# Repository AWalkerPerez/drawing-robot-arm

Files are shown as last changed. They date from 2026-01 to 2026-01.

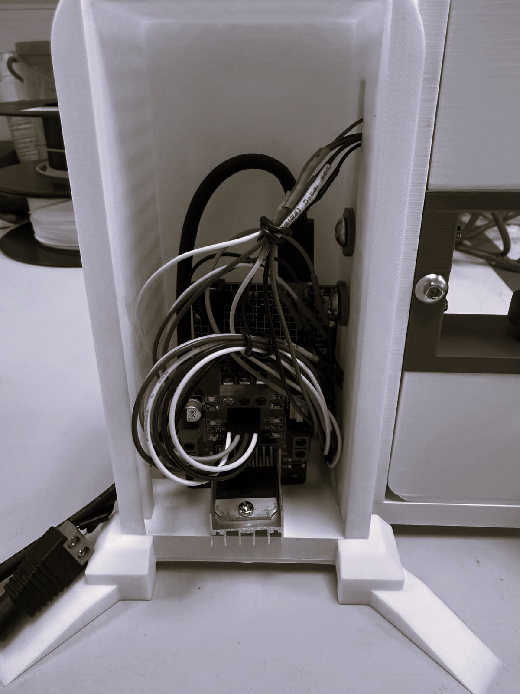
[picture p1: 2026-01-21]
media/photos/wiring_final.jpg

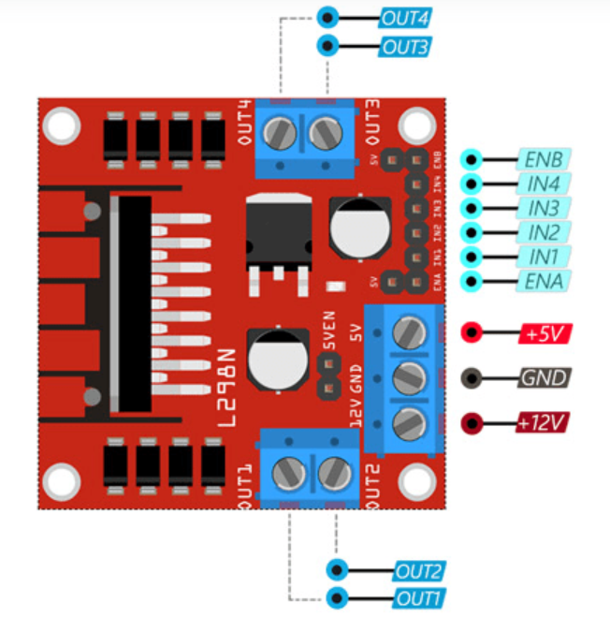
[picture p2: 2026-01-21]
media/diagrams/l298n_pinout.png

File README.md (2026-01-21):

# Small Arm, Big Impact — 2DOF Drawing Robotic Arm

A low-cost 2-degree-of-freedom drawing arm designed for precise motion in a ~156mm x 156mm workspace.
Built with micro servos, an Arduino Uno, and an L298N driver, with analytical IK + PID control and a MATLAB GUI.

## What’s in this repo
- `firmware/` — Arduino code to receive target points and actuate motors
- `matlab/` — GUI + kinematics / plotting scripts
- `cad/` — CAD + printable files (STL/3MF) and assembly notes
- `electronics/` — wiring diagram + parts list
- `report/` — full project report (methods + results)

## Quickstart (typical workflow)
1. Print parts from `cad/`
2. Assemble + wire using `electronics/`
3. Upload Arduino code from `firmware/arduino/`
4. Run the MATLAB GUI in `matlab/gui/` to send (X,Y) targets

## Key methods implemented
- Forward + analytical inverse kinematics
- Differential IK options (Jacobian Transpose / DLS)
- PID tuning per motor
- MATLAB GUI that sends coordinates and plots feedback

## Results
See `report/Final_Applied_Robotics_Report.pdf` for the full evaluation.

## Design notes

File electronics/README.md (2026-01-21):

# Electronics

This folder contains the wiring + component notes for the 2-DOF drawing robot arm.

## What’s in this folder
- `parts_list.md` — exact bill of materials (with quantities)
- `wiring_diagram.png` — wiring diagram for the final build
- `arduino_uno_r4_pinout.png` — Arduino Uno R4 pin reference
- `l298n_pinout.png` — L298N reference pinout (if included)
- `motor_dimensions.png` — motor dimensions (if included)

## System overview
- **Controller:** Arduino Uno R4
- **Motor driver:** L298N dual H-bridge
- **Motors:** 2× DC geared motors with potentiometer feedback
- **Power:** 12V DC supply (12V, 5A)

## Wiring summary (high level)
### Power
1. Connect the **12V supply** to the L298N:
   - Supply **+12V** → L298N `+12V`
   - Supply **GND** → L298N `GND`
2. Connect **Arduino GND** to **L298N GND** (common ground).

> Important: Motors must be powered from the 12V rail through the L298N. Do **not** power motors from the Arduino 5V pin.

### Motors
- Motor 1 → L298N `OUT1` / `OUT2`
- Motor 2 → L298N `OUT3` / `OUT4`

If a motor spins the wrong way, either swap the two motor wires on the output, or invert direction in firmware.

## Arduino pin reference
Use `arduino_uno_r4_pinout.png` as a quick reference for:
- PWM-capable pins (for ENA/ENB)
- Analog inputs (for potentiometer feedback)
- Power pins (5V / GND)

### Control signals (Arduino → L298N)
The L298N uses:
- `IN1, IN2` for Motor 1 direction
- `IN3, IN4` for Motor 2 direction
- `ENA, ENB` for motor speed (PWM)

**Exact pin mapping:** see `firmware/pid_controller/pid_controller.ino` (recommended source of truth).
If you want, you can also document it here once final:

| Signal | L298N pin | Arduino pin |
|---:|---|---|
| Motor 1 PWM | ENA | (fill) |
| Motor 1 dir | IN1 | (fill) |
| Motor 1 dir | IN2 | (fill) |
| Motor 2 PWM | ENB | (fill) |
| Motor 2 dir | IN3 | (fill) |
| Motor 2 dir | IN4 | (fill) |

### Potentiometer feedback (per motor)
Each motor has a potentiometer used for position feedback:
- Pot **VCC** → Arduino **5V**
- Pot **GND** → Arduino **GND**
- Pot **wiper/output** → Arduino **analog input** (e.g., `A0` for motor 1, `A1` for motor 2)

Again, check the `.ino` for the exact analog pins used.

## L298N module notes (common gotchas)
- Many L298N boards have a **5V regulator jumper** (often labelled `5V_EN`).
  - Safest setup: power the L298N logic from the Arduino 5V and only use the 12V rail for motors.
  - If you change jumper settings, double-check the module’s labels so you don’t back-power the Arduino.

- The L298N can get warm. Make sure the heatsink has airflow.

## Troubleshooting
- **Motors don’t move at all**
  - Check common ground (Arduino GND ↔ L298N GND)
  - Confirm 12V is present at the driver input
  - Confirm ENA/ENB are enabled (PWM pin not floating)

- **One motor moves, the other doesn’t**
  - Swap motor outputs to isolate whether it’s wiring vs motor vs code
  - Check that the second motor’s ENB/IN3/IN4 pins match firmware

- **Noisy / jittery feedback**
  - Ensure pot ground is solid
  - Keep pot wires away from motor power wires where possible
  - Shorter wiring helps (direct wiring is good)

## See also
- Firmware: `firmware/`
- MATLAB control/GUI: `matlab/`
- Full write-up: `report/Final_Applied_Robotics_Report.pdf`

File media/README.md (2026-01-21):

# Media

Project visuals used in the root README and report.

## Folders
- `photos/` — real-world prototype photos and GUI output
- `diagrams/` — CAD and reference diagrams
- `plots/` — workspace, accuracy, PID, and manipulability plots
- `demos/` — short MP4 demos

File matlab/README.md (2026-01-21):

# MATLAB

MATLAB code for the 2-DOF drawing robot arm.

This folder contains:
1) A **GUI** that communicates with the Arduino over Serial and plots the motion
2) **Kinematics + analysis** scripts (FK/IK/Jacobian/manipulability) used for offline evaluation and visualisations

---

## Folder structure

Recommended layout:

- `gui/`
  - `GUI.m` — MATLAB GUI: enter a target point (x, y), send to Arduino, plot desired vs actual path

- `control/`
  - `robot_arm_control.m` — offline sandbox for experimenting with control/trajectories (no hardware required)

- `kinematics/`
  - `inverse_kinematics.m` — analytical IK used by the GUI (target x,y → joint angles)
  - `forward_kinematics_version_2.m` — FK used by the GUI (joint angles → x,y for plotting)
  - `forwardKinematics.m` — FK utility (often used by analysis scripts; returns transform / position)
  - `ik_jacobian.m` — Jacobian for 2-link planar model
  - `ik_differential.m` — differential IK update step
  - `Manipulability.m` — manipulability plots + ellipsoids (Jacobian Transpose / DLS)

---

## File entry points (what you actually run)

### Run this (hardware required)
- `gui/GUI.m`  
  Starts the GUI, connects to the Arduino over Serial, sends commands, and plots results.

### Run these (offline / no hardware required)
- `control/robot_arm_control.m`  
  Sandbox for testing trajectories/control ideas locally.
- `kinematics/Manipulability.m`  
  Generates manipulability metrics and ellipsoid plots for Jacobian Transpose and/or DLS (depending on your script settings).

### Helper functions (not run directly)
These are called by the GUI or by the analysis scripts:
- `kinematics/inverse_kinematics.m`
- `kinematics/forward_kinematics_version_2.m`
- `kinematics/forwardKinematics.m`
- `kinematics/ik_jacobian.m`
- `kinematics/ik_differential.m`

---

## Requirements
- MATLAB (R2020b+ recommended)
- Serial support (uses `serialport`, built-in)

---

## Quickstart (Hardware + GUI)

1) Upload the Arduino firmware first  
See: `firmware/README.md`

2) Open MATLAB and set the current folder to `matlab/`

3) Add this folder + subfolders to your MATLAB path:
```matlab
addpath(genpath(pwd))
```
4) Edit the COM port in gui/GUI.m (it’s hardcoded):
```
matlab
s = serialport("COM11", 9600);
```
Change "COM11" to the port your Arduino shows up as.

5) Run the GUI:
```
matlab
GUI
```
---
## What the GUI does (high level)
- Takes a desired end-effector target (x, y)
- Computes joint targets using inverse_kinematics.m
- Sends joint targets over Serial to the Arduino firmware
- Reads measured joint angles back from the Arduino
- Computes the measured end-effector position using forward_kinematics_version_2.m
- Plots desired vs actual
---
## Serial protocol (matches the firmware)
### MATLAB → Arduino (command)
The Arduino parses a command that starts with a character and ends with ;:
`C<theta1>,<theta2>;`
Example:
`C45.00,10.00;`
### Arduino → MATLAB (telemetry)
Arduino streams lines like:
`c<i>,<theta1_meas>,<theta2_meas>`
Example:
`c12,44.63,9.92`
Baud rate: **9600**
---
## Offline analysis scripts (no hardware required)
### Manipulability / ellipsoids
Run:
```matlab
Manipulability
```
This generates manipulability curves and ellipsoids for Jacobian Transpose and/or Damped Least Squares (DLS) depending on your script settings.

### Differential IK utilities
- `ik_jacobian.m` — compute Jacobian at a configuration
- `ik_differential.m` — compute a single joint update for a desired end-effector delta
- `forwardKinematics.m` / `forward_kinematics_version_2.m` — compute end-effector position from joint angles
---
## Units + conventions (important)
- Keep units consistent across GUI input, IK, and FK:
  - If you input mm, link lengths should be mm.
  - If you input m, link lengths should be m.
- Be consistent about degrees vs radians:
  - If firmware expects degrees, keep MATLAB outputs in degrees (or convert explicitly).
A “wrong looking” plot is almost always unit mismatch.
---
## Troubleshooting
- **GUI runs but nothing moves**
  - Check Arduino firmware is uploaded and running
  - Confirm COM port and baud rate (9600)
  - Close Arduino IDE Serial Monitor (it can lock the port)
- **MATLAB errors: “Undefined function …”**
  - Make sure you ran:
  ```matlab
  addpath(genpath(pwd))
  ```
  from inside the `matlab/` folder
**- Plot looks mirrored / inverted**
  - Swap sign conventions in IK/FK or adjust joint angle reference (0° direction)
  - Double-check coordinate frame assumptions (x-right/y-up vs x-right/y-down)
---
## See also
- Firmware upload + pin mapping: `firmware/README.md`
- Wiring + parts list: `electronics/`
- Full project write-up: `report/Final_Applied_Robotics_Report.pdf`

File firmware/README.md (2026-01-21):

# Firmware

Arduino firmware for the 2-DOF drawing robot arm.  
It receives joint angle commands from MATLAB over Serial, runs a PID controller for each motor, and streams back the measured joint angles.

## Location
- Main sketch: `firmware/pid_controller/pid_controller.ino`

## Hardware used
- **Board:** Arduino **Uno R4**
- **Motor driver:** L298N dual H-bridge
- **Motors:** 2× DC geared motors with **quadrature encoder outputs** (A/B)

## How to upload
1. Open `pid_controller.ino` in the Arduino IDE.
2. Select your board:
   - *Arduino Uno R4 Minima* or *Arduino Uno R4 WiFi* (whichever you have)
3. Select the correct **Port**.
4. Click **Upload**.
5. Open Serial Monitor (9600 baud) if you want to view telemetry.

## Pin mapping (as used in the code)

### Motor encoders (quadrature)
| Motor | Encoder A | Encoder B |
|---:|---|---|
| M1 | A3 | A2 |
| M2 | A1 | D11 |

> Note: Encoder A pins use interrupts via `attachInterrupt(...)`. If you change boards/pins, make sure the new pins support interrupts.

### L298N direction pins
| Motor | IN1 | IN2 |
|---:|-----|-----|
| M1 | D4 | D5 |
| M2 | D7 | D8 |

### L298N enable (PWM) pins
| Motor | ENA / ENB | Arduino pin |
|---:|---|---|
| M1 | ENA | D6 |
| M2 | ENB | D9 |

## PID gains (where to change them)
At the top of `pid_controller.ino` you’ll see:

- `Kp_m1`, `Ki_m1`, `Kd_m1`
- `Kp_m2`, `Ki_m2`, `Kd_m2`

Update these values to tune the response.  
There is also an integral windup clamp:

- `windupGuard`

## Serial protocol (MATLAB ↔ Arduino)

### Command format (MATLAB → Arduino)
The Arduino expects joint targets (in **degrees**) in this format:

`C<theta1>,<theta4>;`

Example:
`C45.00,10.00;`

Notes:
- The leading `C` is required.
- Values are parsed as floats.
- The command must end with `;`

### Telemetry format (Arduino → MATLAB)
The Arduino continuously streams:

`c<i>,<theta1_meas>,<theta4_meas>\r\n`

Example:
`c12,44.63,9.92`

Where:
- `i` is a counter
- `theta1_meas`, `theta4_meas` are the measured joint angles (degrees)

## Using with MATLAB
The MATLAB GUI sends commands in the correct `C..., ...;` format and parses `c...` telemetry.

- GUI script: `matlab/gui/GUI.m`
- **Important:** update the COM port in `GUI.m` (it’s currently hardcoded, e.g. `COM11`).

## Troubleshooting
- **Nothing moves**
  - Confirm L298N has 12V power
  - Confirm **common ground** (Arduino GND ↔ L298N GND)
  - Check ENA/ENB pins are connected to PWM pins (D6, D9)
- **One motor spins the wrong direction**
  - Swap OUT wires for that motor on the L298N, or invert direction logic in code
- **No serial data in MATLAB**
  - Confirm baud rate is **9600**
  - Confirm correct COM port and that Arduino IDE Serial Monitor is closed (it can “steal” the port)

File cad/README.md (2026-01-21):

# CAD

## Folders
- `fusion360/` — editable source CAD (Fusion 360)
- `print_files/3mf/` — print-ready 3MF exports (recommended)
- `print_files/stl/` — print-ready STL exports (most compatible)
- `renders/` — images used in the main README

## Notes
3MF files are the easiest way to reproduce the exact prints.
Fusion 360 files are provided for modification/customisation.

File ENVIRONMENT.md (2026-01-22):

# Environment

This project is implemented using **MATLAB** and **Arduino** (no Python dependencies required).

## Tested setup
- **OS:** Windows 10/11 (recommended)
- **MATLAB:** R2020b+ (any recent version should work)
- **Arduino IDE:** 2.x
- **Board:** Arduino **Uno R4** (Minima or WiFi)
- **Motor driver:** L298N dual H-bridge
- **Power supply:** 12V DC, 5A (60W)

## MATLAB requirements
- MATLAB with support for `serialport` (built-in)
- No additional toolboxes are required for the provided scripts

### MATLAB path setup
From the `matlab/` folder:
```matlab
addpath(genpath(pwd))
```
### Arduino requirements
- Install Arduino IDE 2.x
- In **Tools** → **Board**, select:
  - Arduino Uno R4 Minima or Arduino Uno R4 WiFi (depending on your board)
- Select the correct **Port**
- Upload: `firmware/pid_controller/pid_controller.ino`

### Serial communication
- Baud rate: **9600**
- The COM port is hardcoded in `matlab/gui/GUI.m` and must be updated to match your machine (e.g., `COM5`, `COM11`, etc.)

### File formats (CAD)
- Editable Fusion 360 exports: `.f3d` (single design) / `.f3z` (assembly)
- Print exports: `.3mf` and/or `.stl`

### Notes / common issues
- Close the Arduino IDE Serial Monitor when running the MATLAB GUI (it can lock the serial port).
- Ensure a **common ground** between the Arduino and motor driver.
---
## Setup (Quickstart)
This is the fastest path from cloning the repo to running a demo.
### 1) Hardware + wiring
**1.** Assemble the robot (see the report for mechanical build context).

**2.** Wire the electronics:
  - See `electronics/README.md`
  - Use `electronics/wiring_diagram.png`
  - Use `electronics/arduino_uno_r4_pinout.png` as a pin reference.

**Power checklist**
- 12V supply powers the L298N (+12V and GND)
- Arduino and L298N share a common GND
- Motors connect to L298N outputs (OUT1/OUT2 and OUT3/OUT4)

### 2) Upload firmware (Arduino)
**1.** Open Arduino IDE.

**2.** Open: `firmware/pid_controller/pid_controller.ino`.

**3.** Select your board (Uno R4 Minima/WiFi) and Port.

**4.** Click **Upload**.

### 3) Run MATLAB GUI
**1.** Open MATLAB.

**2.** Set current folder to `matlab/`.

**3.** Add paths:
```matlab
addpath(genpath(pwd))
```
**4.** Open `matlab/gui/GUI.m` and update the COM port:
```matlab
s = serialport("COM11", 9600);
```
**5.** Run:
```matlab
GUI
```
### 4) Demo
- Enter a target point (x, y) in the GUI and press **Send**
- The GUI sends commands to the Arduino and plots desired vs actual motion
---
### Troubleshooting
- If MATLAB can’t connect to the serial port:
  - Close Arduino IDE Serial Monitor
  - Double-check COM port and baud rate (9600)
- If motors don’t move:
  - Confirm 12V supply is live at the L298N
  - Confirm common ground (Arduino GND ↔ L298N GND)
  - Confirm ENA/ENB and IN1–IN4 wiring matches the firmware pin mapping

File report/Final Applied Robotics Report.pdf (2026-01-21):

SMALL ARM, BIG IMPACT: AL THE DRAWING ROBOTIC ARM

### Andrea Walker Perez Kings College London

ABSTRACT
This paper presents the design and development of a two-
degree-of-freedom robotic arm | tailored for | precise
applications within a 156 mm x 156 mm workspace. The arm demonstrates potential for use in medical scenarios such as fine motor surgical tasks and precision prototyping. The aim is to create an affordable, compact system integrating efficient control strategies. The robot integrates micro servo motors and a custom CAD design, controlled by an Arduino Uno and L298N motor controller. Forward and inverse kinematics were derived for accurate motion planning, and PID tuning was employed to optimise the stability and accuracy of the system. Experiments were conducted to evaluate the arm’s performance under varied loads, PID settings, and predefined trajectories. The robotic arm achieved an average deviation of less than 2 mm in accuracy tests and exhibited reliable repeatability under varying conditions. Experimental results demonstrate a clear trade-off between speed and precision, with optimal PID gains minimising oscillations and ensuring stability.
This robotic system provides a foundation for low-cost, high-precision applications in robotics. Future enhancements will address system limitations such as oscillations under high loads and explore dynamic control strategies to expand its operational capabilities.

### 1. INTRODUCTION

Robotics in precision applications, particularly in medical fields, is a fast-evolving domain. With increasing demand for accuracy, affordability, and adaptability, two critical questions emerge:
1. Can robotic systems replicate the fine motor skills required in precision tasks such as surgeries?
2. How can low-cost robotic arms maintain high precision and stability under varying conditions?
Advancements in robotics have proven their ability to perform intricate tasks traditionally reserved for humans. The Da Vinci Surgical System has revolutionised surgery by enabling minimally invasive procedures with millimetre-scale accuracy [1]. Low-cost solutions incorporating modern control techniques, such as PID and kinematic modelling, make robotic precision more accessible.
While promising, affordability often comes at the cost of robustness and precision. Unlike high-end systems, low-cost robotic arms frequently struggle with stability under dynamic conditions and precision in repeatability. Additionally,
integrating | compact | designs | with | high-performance
electronics and motors remains challenging.
The integration of efficient control strategies with modular hardware designs offers a pathway to making robotic precision more accessible. By addressing stability and precision trade-offs, low-cost robots can extend their applications beyond prototyping into fields like medical assistance and microfabrication.

### 1.1. Aim and Objectives

The aim was to design, build, and evaluate a two-degree-of-freedom robotic arm capable of precise drawing operation within a defined workspace.
Specific objectives include:
- Develop a modular CAD design integrating micro servos, thrust bearings, and a secure pen holder.
- Implement forward and inverse kinematics for accurate motion planning.
- Optimise PID control to balance speed, precision, and stability.
- Evaluate performance through experiments focusing on accuracy, speed, and load-bearing capacity.

### 2. METHODOLOGY

This section details the design, development, and testing methodologies for the robotic system designed for medical applications. The focus was on achieving high precision, stability, and a wide range of motion. The system combines CAD design, hardware integration, kinematic analysis, control strategies, and experimental validation.

### 2.1 CAD Design and 3D Printing

The robotic arm was designed as a parallel SCARA configuration with an extension holding the end effector, tailored for precision and compactness. The CAD design comprises three main components: the base, the arm, and the protective housing. The arm features four links: two vertically stacked links directly connected to motors, maximising the range of motion and compactness, and two additional links extending the reach of the end effector. The parallel arrangement optimises workspace usage while maintaining high accuracy and mechanical robustness.
The base provides a robust foundation, securely housing the motors and control electronics to ensure consistent performance during operation. To enhance the grounding of the arms, the motor-connected links were equipped with ratcheting gears, allowing manual adjustments without affecting the motor’s position.

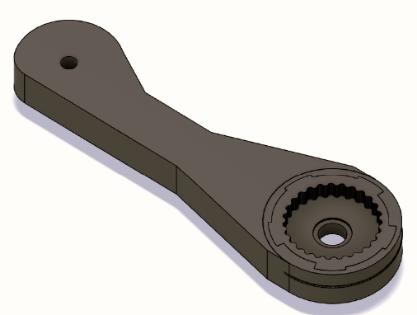
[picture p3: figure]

Figure 1 Ratcheting Gear Design

One motor-driven link is connected to an intermediate one, supporting the pen-holding assembly. In contrast, the final link bridges the end-effector and the second motor-driven link, completing the parallel SCARA-like mechanism. Figure 1 illustrates the arm’s configuration.
The protective housing was designed to enclose the Arduino Uno and motor drivers, offering environmental protection while ensuring accessibility for maintenance. Features like a sliding door allow for easy access to electronics without compromising the overall design’s integrity.
The design underwent iterative refinement using Fusion 360, where simulations validated key aspects such as mechanical strength, range of motion, and component interactions. After finalising each design, the CAD models were exported in the .3mf file format, which preserves intricate geometries and ensures compatibility with the 3D printing process.
3D printing was performed using Bamboo Studio, where the .3mf files were imported for slicing and G-code generation. The printing parameters were selected to balance dimensional accuracy and structural integrity. A layer height of 0.2 mm was used to achieve a smooth surface finish, while an infill density of 40% provided the necessary strength and reduced material usage. PLA was chosen as the primary material due to its favourable mechanical properties, lightweight nature, and ease of use. Supports were strategically applied to maintain precision during printing. Preliminary test prints were conducted to evaluate the dimensional accuracy of the 3D printed components compared to the CAD designs on Fusion 360. These tests ensure that the printed dimensions closely matched the intended specifications and allowed for fine-tuning of the design to account for such discrepancies, ensuring that critical dimensions met the necessary tolerances for proper assembly and functionality.

### 2.2 Hardware Integration

The robotic system’s hardware was designed with precision and compactness in mind. At its core, the system comprises two micro servo motors controlled by an Arduino Uno, which interfaces with an L298N motor driver. This integration was essential for ensuring precise motion control of the robotic arm. The Arduino Uno serves as the central control unit, executing commands and managing the motor signals. It connects directly to the L298N motor driver through its digital pins. These connections include ENA, ENB, IN1, IN2, IN3, and IN4, which transmit the necessary Pulse Width Modulation (PWM) and directional signals for the motors.

The motors themselves are powered via the OUT1/OUT2 and OUT3/OUT4 outputs of the L298N, ensuring smooth operation. The L298N receives power from an external 12V supply, with its GND connected to both the Arduino and the supply for common ground.
To enhance stability and efficiency, thrust bearings were used in the joints directly connected to the motors. These bearings handle the axial loads effectively, reducing wear and tear while transmitting torque reliably to the robotic arm. For the other joints, ball bearings were chosen for their ability to minimise friction and ensure smooth rotational motion, crucial for maintaining precision during operation.
Wiring was carefully organised and routed through protective housing to minimise clutter and facilitate troubleshooting. Cable ties were used to secure connections, and wires were routed away from moving parts to prevent damage during operation. The servos were powered by an external 5V power supply, ensuring sufficient torque and consistent operation without overloading the Arduino’s onboard regulator.
A simplified schematic wiring diagram is provided in Figure 2, illustrating the connections between the components. The diagram highlights the integration of the Arduino, L298N motor driver, motors, and the external power supply, with clear labelling of all pins and connections. This setup ensures reliability and ease of replication.

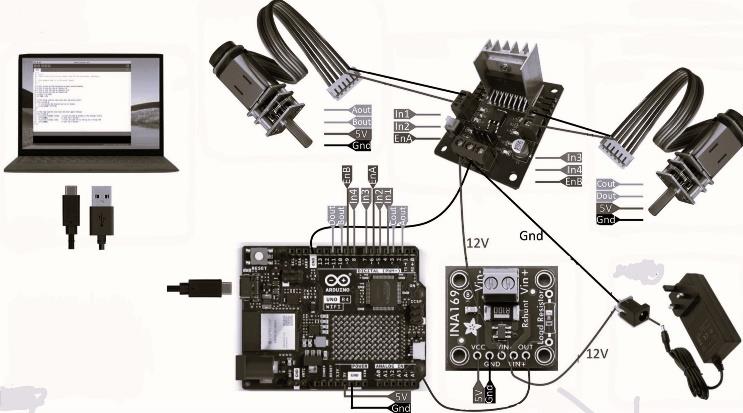
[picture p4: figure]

Figure 2 Wiring Diagram

### 2.3 Kinematics

2.3.1. Forward Kinematics
Forward kinematics was used to calculate the end-effector’s position in the 2D workspace based on the joint angles (θ1 and θ2) and the lengths of the robot arm’s links directly connected to the motors (l1 and l4).
The end-effector’s coordinates (x, y) were computed using the following equations:
x = l1cosθ1 + l4cosθ4 +lexcosθex
= l2cosθ2 + l3cosθ3 + lexcosθex y = l1sinθ1 + l4sinθ4 + lexcosθex
= l2sinθ2 + l3sinθ3 + lexsinθex Here, l1 and l4 represent the two links extending from the motors, while l2, l3, and lex are the links connecting the dependent joints to the end-effector. The angles θ1 and θ4 are measured relative to the horizontal baseline and serve as the primary independent joint angles. The dependent angles, θ2, θ3, and θex, are proportional to the main angles, with θ2 = θex = θ4 and θ3 = θ1.
The workspace of the robotic arm was analysed using forward kinematics, considering the lengths of the links and the joint angle limits. As shown in Figure 3, the theoretical workspace, represented by the dotted curve, highlights all reachable positions. Within this theoretical workspace lies the operational workspace, a 156 mm x 156 mm square area selected for precision tasks. The operational workspace has an offset of approximately 110 mm from the centre of the robot, corresponding to the length of l1, which creates a gap between the centre and the reachable area.

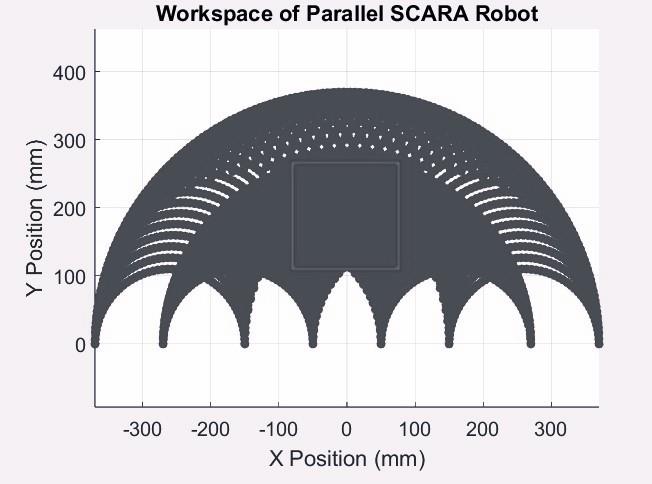
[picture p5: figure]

Figure 3 Theoretical and Operational Workspaces of the Robotic Arm

The derivation of the forward kinematics equations and methodology for determining the workspace were guided by principles discussed in the work of Le et al. [2], which provide a foundational approach to analysing planar parallel manipulators.
2.3.2. Analytical Inverse Kinematics
The analytical inverse kinematics for the robotic arm were derived to calculate the required joint angles (θ1 and θ4) based on the derived end-effector position (x,y) within the 2D workspace. This method relies on trigonometric relationships and the geometry of the parallel SCARA configuration, ensuring high precision in computing the joint parameters. The inverse kinematics equations were derived using the lengths of the robot’s links and the constraints imposed by the arm’s geometry. These equations ensure that each desired position is mapped to a unique set of joint angles. The process involves calculating the distance from the origin to the intersection between both paths:
r = √x
2 + y
2 | (1)
Then, using the cosine rule, the intermediary angles are derived:

A = cos⁻¹

(

l1

2+r
2−l4

2

2l1r

) | (2)

B = cos⁻¹

(

l1

2+l4

2+r
2

2l1l4

) | (3)
E = 180 − A −D | (4)
F = B − E | (5)

To account for the offset:
w = (l5 − l4
) cos(F) | (6)

z = (l5 − l4

) sin(F) | (7)

The corrected position of the end-effector point is:

x2 = x − w | (8)

y2

= y − z | (9)

The angle D represents the orientation of the target position relative to the origin. To ensure the robot operates within its physical constraints and avoids unsafe configurations, the following conditions are applied:
- For
(x ≥ 0, y ≥ 0):D = tan⁻¹
(

y
x
⁄ ) | (10)
- For

(x < 0, y ≥ 0):D = 180 − tan⁻¹
(

y
−x
⁄ ) | (11)
- For

(x ≥ 0, y < 0):D = tan⁻¹
(

y
x
| | ⁄ ) | (12)
- For
(x < 0, y < 0): This configuration is unreachable and should return and error.
Limiting D ensured that the computed angles remain within the robot’s workspace and prevents it from attempting to move to positions that could damage the hardware. Finally, the angles G and H, required to resolve the kinematics of the arm, are calculated using the cosine rule as follows:

G = cos⁻¹

(

r

| 2+r2

2−(l5−l4
| | )
| | 2
| 2rr2 | ) | (13)

H = cos⁻¹

(

l2

| 2+r2 2−l1

2

| 2l2r2
) | (14)

Finally, the joint angles are defined as follows:
θ1 = D +A | (15) | θ4 = (D +G) −H | (16)

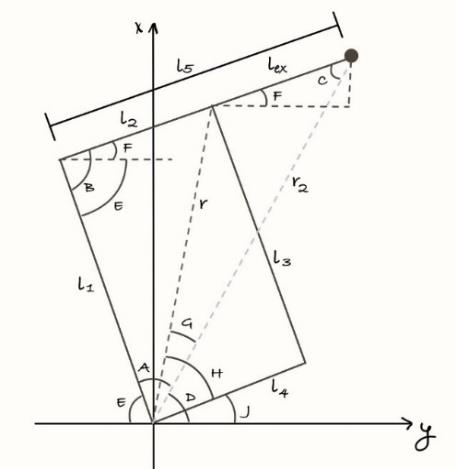
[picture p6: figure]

Figure 4 Analytical Inverse Kinematic Diagram

The derived equations account for the dependency of the secondary joint angles on the primary joint angles as mentioned in section 2.3.1. This dependency ensures that the
arm | operates | cohesively, | maintaining | its | parallel
configuration. The final equations were validated through MATLAB simulations, where test cases confirmed that the computed angles accurately positioned the end-effector within the desired workspace. In section 3 you can see the GitHub repository link with all the code implementing this.
2.3.3. Differential Inverse Kinematics and Manipulability The robotic arm’s motion and manipulability were analysed using differential inverse kinematics methods, specifically the Jacobian transpose method and the damped least squares (DLS) method. These approaches were implemented to ensure accurate tracking of the desired end-effector trajectories while maintaining stability and avoiding singularities within the workspace.
The Jacobian matrix, derived as a function of the joint angles and link lengths, provides a relationship between the joint velocities and the end-effector velocity in Cartesian space [3]. Its form is given as:

J = [

−r1 sin(θ1

) −r2 sin(θ2

)
r1 cos(θ1
| ) | −r2 sin(θ2

)

] | (17)

, where r1 and r2 represent the respective link lengths. This matrix not only facilitates the computation of joint velocities but also provides insight into the manipulability of the robotic arm at various configurations. The manipulability at a specific configuration is defined as the square root of the determinant of JJT
, which quantifies the arm’s ability to perform precise motions in multiple directions. Higher manipulability values correspond to greater ability and flexibility in motion.
The DLS method computed joint velocity corrections, enhancing numerical stability near singularities [3]. This method modifies the pseudo-inverse of the Jacobian by introducing a damping term, ensuring that the control law remains stable even in configurations where the Jacobian matrix approaches singularity [3]. The control law is defined as:

∆q = (J

T
J +λ

2
I)

−1
J

T
| | e | | | (18)

, where ∆q represents the joint velocity corrections, e is the error between the desired and current end-effector positions, λ is the damping factor, and I is the identity matrix. The damping factor was tuned experimentally to balance responsiveness and stability, ensuring smooth trajectory tracking.
As an alternative, the Jacobian transpose method was used. This approach simplifies computation by avoiding matrix inversion, making it computationally efficient but less robust near singularities [3]. The control law for the Jacobian transpose method is expressed as:
∆q = kJ

T
e | | | | | (19)

, where k is the gain factor. While Jacobian transpose is advantageous for its simplicity, it was primarily used for configurations away from singularities, where robustness was less critical.

### 2.4 PID Control

PID control was implemented to ensure smooth, precise, and responsive positioning of the servo motors in the robotic arm. The control law is expressed as

u(t) = Kpe(t) + Kd

| | de(t)
| | dt
+ Ki ∫ e dt + | (20)

, where e(t) is the error between the desired and actual position of the motor [4]. Kp, Ki, and Kd are the proportional, integral, and derivative gains. Graph 1 provides theoretical damping scenarios that may arise when tuning the PID gains and serves as a guide to understanding the influence of each. In an underdamped response, the system is sensitive to errors and tends to overshoot the setpoint with oscillations before eventually settling. This scenario typically arises when the proportional gain is too high, resulting in a system that reacts aggressively to deviations. In contrast, an overdamped response is characterised by a slow and conservative approach to the setpoint, with no overshoot. This behaviour often results from overly cautious tuning, such as a low Kp or an excessively high Kd. A critically damped response lies at the boundary between these two extremes, where the system reaches the setpoint without oscillating. However, it is often too slow for dynamic systems that require both speed and precision.
The dashed curve on the graph represents an optimally tuned PID system, which achieves a slightly underdamped response. This provides a balanced trade-off between responsiveness and stability, allowing the system to reach the setpoint quickly with minimal overshoot and without significant oscillations. This is typically the desired behaviour for robotic systems performing precision tasks such as drawing.
Each component of the PID controller contributes uniquely to the system’s behaviour. The proportional term reacts proportionally to the current error, providing immediate
corrective | action. | While | increasing | Kp | improves
responsiveness, it also risks overshoot and instability if set too high. The integral term addresses steady-state errors by considering the accumulation of past errors, correcting persistent offsets. However, excessive Ki can introduce oscillations due to overcompensation. Finally, the derivative term predicts future errors by responding to the rate of change of the error, effectively dampening oscillations and smoothing the system’s approach to the setpoint.
Using this theoretical framework as a guide, the PID tuning process was conducted systematically. The process began with tuning Kp, while Ki and Kd were initially set to zero. Kp was incrementally varies within range of 1 t. Once a satisfactory value was determined, Ki was introduced between 0 and 20. Finally, Kd was incorporated to refine the transient response within a range of 0 to 20.
This structured approach ensured that each gain was tuned in isolation before combining them to achieve a balanced and effective PID control.
The PID tuning process aimed to optimise the PID parameters to balance speed and accuracy in the robotic arm’s movements. The process began with a focus on the Kp, which varied incrementally from 1 to 50 whilst keeping Ki = 0 and Kd = 0.
The integral gain (Ki) was introduced to mitigate overshoot and address steady-state errors, ranging from 0 to 20. Then kd ranging from 0 to 20.

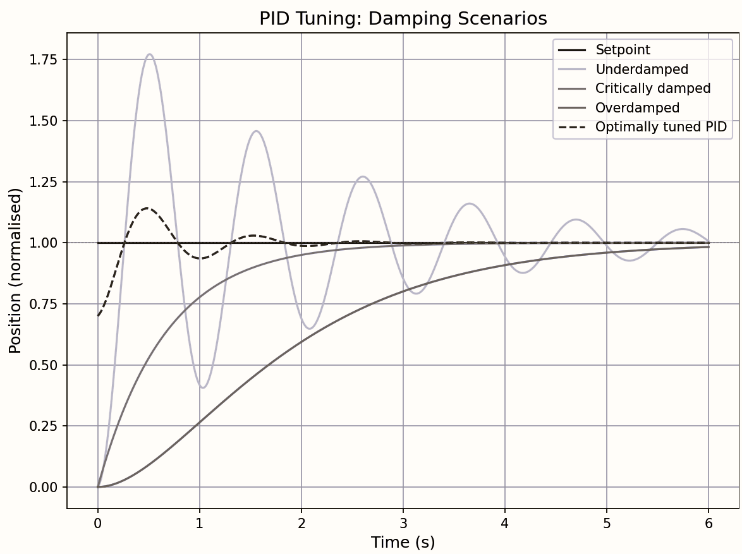
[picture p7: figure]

Graph 1 Damping Scenarios during PID Tuning (adapted from [5])

### 2.5 High-Level Control and GUI Implementation

The high-level control of the robotic system involves a structured workflow that bridges the gap between user commands and precise robotic movements. Figure 5 shows this workflow, which includes command input via a graphical user interface (GUI), real-time data processing, and the computation of joint angles for robot motion using inverse kinematics.

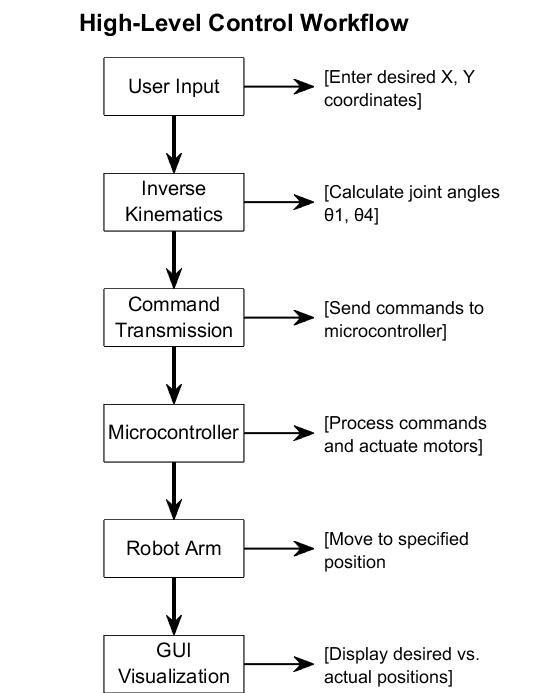
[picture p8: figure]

Figure 5 High-Level Control Workflow of the Robotic System

The GUI, developed in MATLAB, allows users to input desired Cartesian coordinates (X, Y) for the robot’s end-effector position. These inputs are processed to compute the required joint angles (θ1, θ4) using the analytical inverse kinematics method. Computed angles are then formatted into commands and transmitted to the microcontroller via serial
communication. | On | receiving | commands, | the
microcontroller allows the robot to move to the specified position. Simultaneously, the robot’s actual position, derived using forward kinematics, is sent back to the GUI for real-time plotting and comparison with the desired position. The GUI interface features input fields for X and Y coordinates, a send button for command transmission, and a dynamically updating plot area for visualising the robot’s motion, as shown in Figure 6. Additionally, a real-time data stream from the microcontroller updates the end-effector position at a fixed rate, enabling continuous feedback during operation.

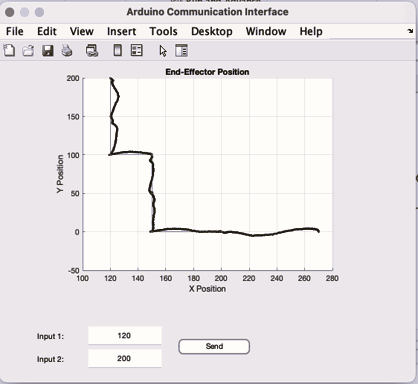
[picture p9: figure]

Figure 6 GUI Interface

The GUI was critical in supporting the experiments described in section 2.6. By enabling precise position control and real-time monitoring, it facilitated the execution of the
experiments. | The | MATLAB | code | for | the | GUI
implementation is included in the GitHub repository linked at the end of section 3.

### 2.6 Experimental Design

Two experiments were designed to evaluate the robot’s performance.
2.6.1. Accuracy Test
The first experiment was conducted to evaluate the robotic arm’s precision in reaching predefined target positions within its workspace. Eight target positions were selected strategically to cover various regions of the workspace, including central locations, edges, and corners. The target positions were defined by their coordinates (X desired, Y desired) and were chosen to ensure a comprehensive assessment of the arm’s ability to accurately traverse its full range of motion.
The robotic arm was programmed to move to each target position using the inverse kinematics model developed in section 2.3.2. Upon reaching a target position, the arm’s actual coordinates (X actual, Y actual) were measured manually using a digital calliper. These measurements were taken at the end-effector, ensuring high precision in capturing the arm’s true location. The deviation between the desired and actual coordinates was recorded for each position.
To assess repeatability and consistency, the experiment was repeated four times for each target position. Between trials, the arm was reset to a neutral home position to ensure the results reflected the arm’s ability to accurately reach the target rather than any systematic drift or accumulated error. The data from these tests were used to calculate the positional error at each target, as well as the mean and standard deviation of the errors across all trials.
2.6.2. Speed vs. Accuracy Test
The second experiment was designed to investigate the trade-off between movement speed and positional accuracy. This test aimed to evaluate how varying the PID controller’s gains affects the arm’s ability to move quickly while maintaining precision. By tuning the proportional, integral, and derivative gains, the speed of the arm’s movements could be increased or decreased, influencing its ability to accurately reach a target. For this test, a subset of the target positions used in the accuracy test was selected, focusing on positions that represented both central and edge locations within the workspace. The PID gains were incrementally adjusted to achieve three different speed settings: low speed (high damping, conservative motion), medium speed (balanced damping and responsiveness), and high speed (low damping, aggressive motion). Each speed setting represented a unique combination of Kp, Ki, and Kd, as determined during the tuning process described in section 2.4. At each speed setting, the arm was programmed to move to the predefined target positions, and its actual coordinates (X actual, Y actual) were recorded as in the accuracy test. The positional error was calculated for each target and analysed to identify any trends between movement speed and accuracy. The experiment was repeated three times for each speed setting to ensure the results were consistent and reliable. In addition to recording positional errors, the time taken to move from the home position to each target was measured using a stopwatch. This allowed for a direct comparison of movement speed and accuracy. This experiment aimed to quantify the relationship between speed and accuracy, highlighting the influence of PID tuning on the robotic arm’s performance.

### 3. RESULTS 3.1 Final CAD Design, 3D Printing, and Wiring

The robotic arm was successfully designed, fabricated, and assembled, meeting the specified requirements for precision, functionality, and ease of integration. The CAD model, shown in Figure 8, was developed using Fusion 360 and features a compact and modular design that optimises workspace use while ensuring structural stability. The arm incorporates a 2DOF mechanism, enabling precise movements within the 156 mm x 156 mm workspace. Integrated cable routing channels and secure mounts for the micro servo motors were included to minimise wire entanglements and improve reliability. Additionally, the
design | emphasised | modularity, | allowing | individual
components to be replaced or upgraded with minimal effort.

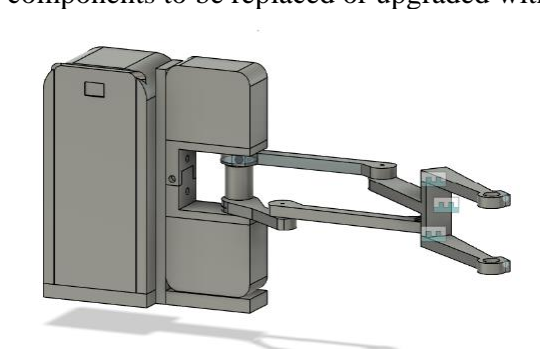
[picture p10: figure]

Figure 7 Final CAD Design in Fusion 360

Once the CAD design was finalised, the robotic arm components were fabricated using 3D printing. The printed model is displayed in Figure 9. The components were printed using PLA, selected for their balance between lightweight properties and sufficient structural strength. The 3D-printed parts demonstrated excellent dimensional accuracy, ensuring proper alignment and fit during assembly. No post-processing was required, as the tolerances were adhered to during the design phase.

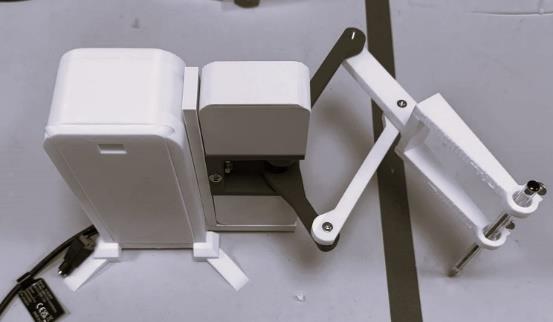
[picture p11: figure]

Figure 8 Final 3D Printed Robotic Arm

The hardware and wiring were organised within the base of the robotic arm, as shown in Figure 10. The design of the base provided sufficient space for all control electronics, including the Arduino Uno, L298N motor controller, and additional components. Wiring was routed through the channels incorporated into the CAD model, ensuring a tidy and secure layout. This approach reduced clutter and minimised the risk of disconnections or signal interference during operation. Cooling considerations were also considered, with the arrangement allowing sufficient airflow around the components.

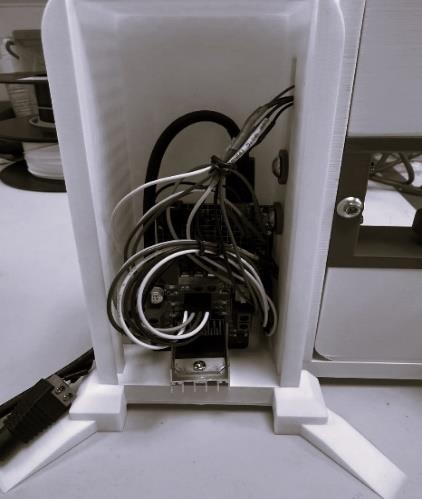
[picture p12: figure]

Figure 9 Final Wiring

### 3.2 Analytical vs Differential Inverse Kinematics

The performance of the robotic arm was evaluated using three methods for computing joint angles and trajectory tracking: analytical inverse kinematics, the Jacobian Transpose method, and the Damped Least Squares (DLS) method. Each method was assessed based on its ability to compute joint
angles, | track | desired | trajectories, | and | maintain
manipulability. The analytical inverse kinematics method provided direct computation of joint angles using geometric and trigonometric relationships. The results, illustrated in Graph 2, demonstrate the arm configuration aligning precisely with the desired position within the workspace. This method generated exact solutions for all tested target positions, provided they were within the workspace and not near singularities.

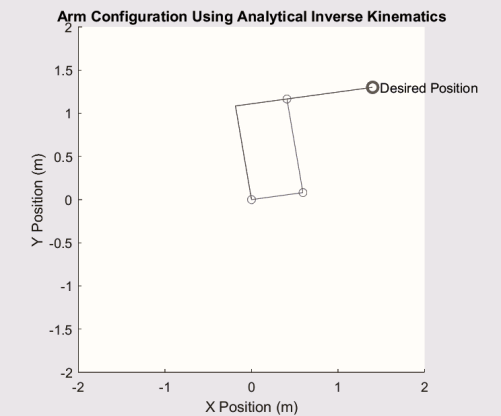
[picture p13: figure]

Graph 2 Analytical Inverse Kinematics Output

The Jacobian Transpose method uses an iterative approach to compute joint angle corrections by multiplying the Jacobian matrix transpose with the positional error. Graph 3 depicts the robot arm’s motion, and the manipulability of ellipsoids generated during trajectory tracking using this method. The manipulability values computed along the trajectory are shown in Graph 4, which highlights changes in manipulability as the arm crosses various configurations.

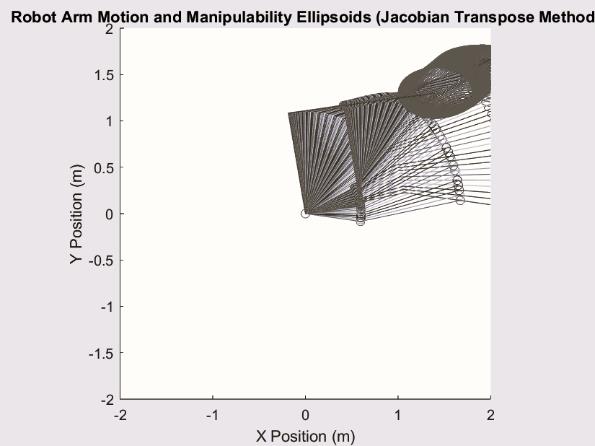
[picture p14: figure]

Graph 3 Jacobian Transpose Output

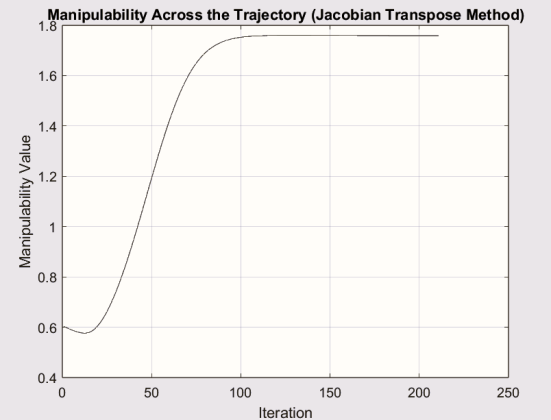
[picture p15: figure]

Graph 4 Manipulability when using Jacobian Transpose

The Damped Least Squared (DLS) method incorporated a damping factor to stabilise the pseudo-inverse of the Jacobian matrix, allowing it to handle singularities more effectively. The motion and manipulability of ellipsoids produced using this method are presented in Graph 5, showing smoother and more consistent ellipsoids compared to the Jacobian Transpose method. Graph 6 illustrates the manipulability values along the trajectory when using the DLS method, which remained stable across all configurations tested.

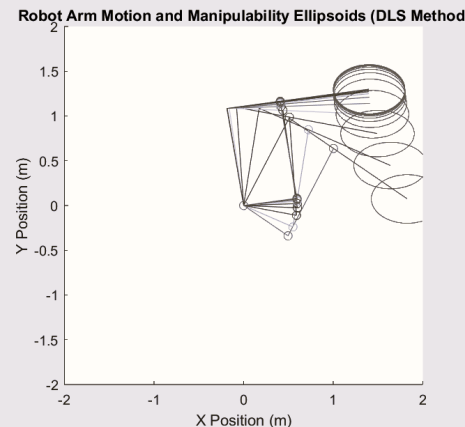
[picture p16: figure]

Graph 5 DLS method Output

Graph 6 Manipulability when using DLS method

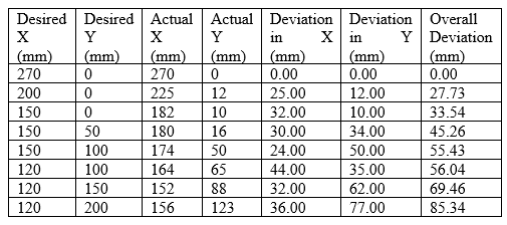
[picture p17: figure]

The MATLAB code for implementing these methods is included in the GitHub repository link at the end of this section.

### 3.3. PID Tuning

The results of the PID tuning tests for the robotic arm are summarised in the table below. The table includes the system response metrics for different combinations of Kp, Ki, and Kd gains, tested on each motor. Key performance metrics measured include the steady-state value, steady-state error, rise time, peak time, peak overshoot, and settling time.

Table 1 PID Tuning Results

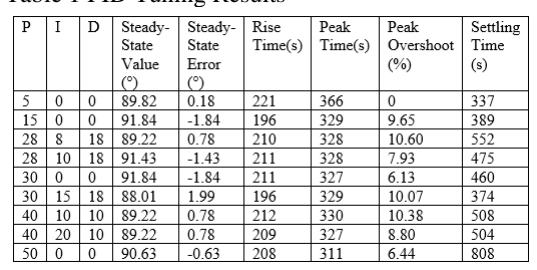
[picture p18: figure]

The corresponding system response graphs for each tuning configuration are presented in Appendix A in Graphs 8-14, showing the angular position versus time for both motors under each set of gains. Optimal PID gains are 28-10-18 for motor 1 and 25-6-18 for motor 2 shown visually in Graph 8.

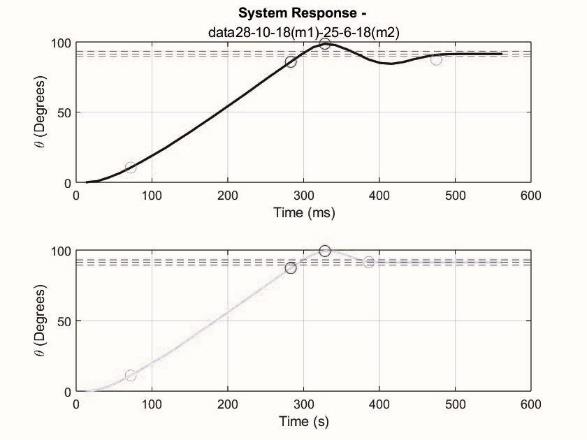
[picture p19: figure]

Graph 7 PID Response for Motor 1 and Motor 2 with PID Gains 28-10-18 and 25-6-18 respectively

### 3.2 Accuracy Test

Table 2 contains the desired and actual positions when sent to multiple points for one of the iterations. It also contains the deviation in each axis and the overall deviation. Graph 9 shows visually all desired and actual positions in that same iteration.
Graph 8 is a bar graph summarising the average deviation for each position.
The average deviation across all trials was calculated as 4.5 mm in the X-axis and 6.7 mm in the Y-axis.

Table 2 Actual and Desired Positions from the robot when going to different points for the accuracy test

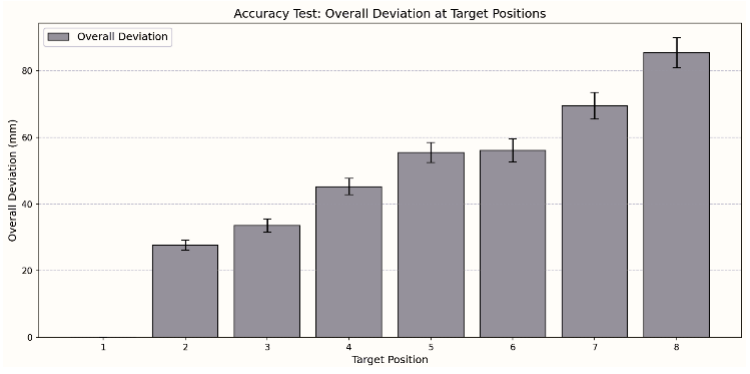
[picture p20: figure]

Graph 8 Overall Deviation of Target Positions from the Accuracy Test

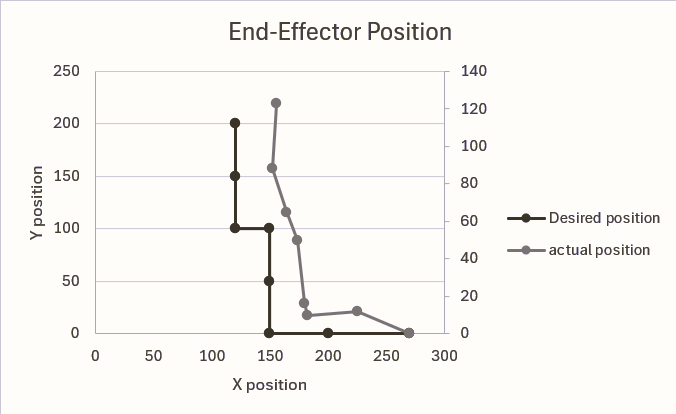
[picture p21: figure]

Graph 9 Desired and Actual Position of the Robot in one iteration when going to different points

### 3.3 Speed vs. Accuracy Test

The speed vs. accuracy test was conducted to evaluate the robotic arm’s performance under different PID gain configurations. The results were analysed in terms of the time taken to reach each target position and the overall deviation from the desired coordinates. The data for all tests of PID gain configurations is summarised in Table 4, which presents the actual end-effector coordinates, the time taken to reach the target, and the overall deviation.

Table 3 PID Gain Results for the Speed vs Accuracy Test

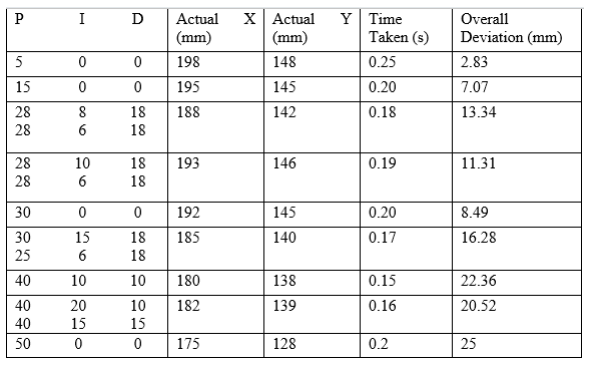
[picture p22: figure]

Lower proportional gain (Kp = 5) resulted in a minimal overall deviation of 2.83 mm but required the longest time of 0.25 seconds to reach the target. As Kp increased, the system responded more quickly, with a minimum time of 0.15 seconds recorded for Kp = 40 (for both motors). However, higher gains also resulted in increased deviations, with the largest overall deviation of 25 mm occurring for Kp = 50. The time taken for each PID gain is illustrated in Graph 10, showing a general trend of decreasing time as the proportional gain increases. The overall deviation for each PID gain is displayed in Graph 11, which highlights a trade-off between speed and precision, as higher gains led to larger deviations.

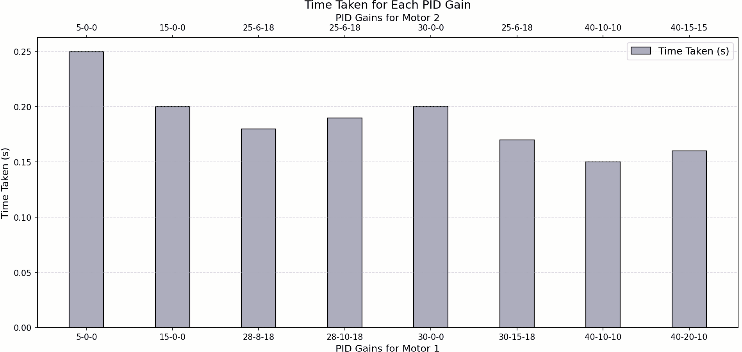
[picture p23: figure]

Graph 10 Time Taken to settle for each PID gain

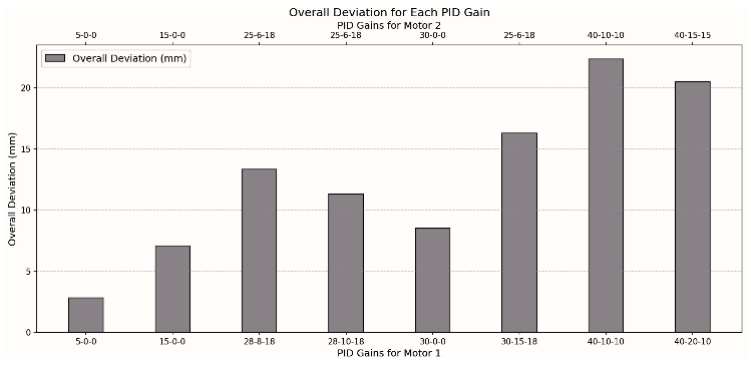
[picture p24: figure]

Graph 11 Overall Deviation for each PID gain

GitHub Link: https://github.com/leastetie/Team-5

### 4. DISCUSSION 4.1 Kinematics

The kinematic methods explored included analytical inverse kinematics, the Jacobian Transpose, and the DLS method, each offering distinct advantages and limitations.
The analytical inverse kinematics method provided precise joint angle computations for all target positions within the robot’s workspace, using geometric relationships and trigonometric functions. Its direct, non-iterative approach ensures fast and accurate solutions, making it well-suited for fixed-geometry tasks like drawing. However, it is limited by workspace constraints and becomes unreliable near singularities.
The Jacobian Transpose method, while computationally efficient and adaptable for real-time applications, exhibited reduced performance near singular configurations due to diminished manipulability. This issue aligns with findings in the literature, which highlight the Jacobian Transpose
method’s | sensitivity | to | configurations | with | low
manipulability [2].
The DLS method addressed these limitations by introducing a damping factor, stabilising solutions near singularities and ensuring smoother and more consistent manipulability across trajectories [2]. However, both iterative methods required greater computational effort than the analytical approach. Given the precision and efficiency required for a drawing arm robot, the analytical inverse kinematics method was selected. Its ability to compute joint angles directly without iterative adjustments ensures rapid and accurate path generations, which is ideal for well-defined workspace and static constraints of this application

### 4.2 PID Tuning

The PID tuning process focused on optimising Kp, Ki, and Kd to achieve a balance between response speed, stability, and overshoot. Our findings indicate that lower proportional gains (Kp) resulted in minimal steady-state errors but led to prolonged rise and settling times. Conversely, higher Kp values enhanced response speed but introduced significant overshoot. Adjusting the integral gain (Ki) influenced the system’s ability to eliminate steady-state errors. Lower Ki values resulted in slower correction of persistent errors, whereas higher Ki values increased the likelihood of oscillations and instability. Similarly, the derivative gain (Kd) played a critical role in damping oscillations. Lower Kd values allowed overshoot to persist, while excessively high Kd values could cause the system to overreact to changes, leading to excessive damping and slower responses. The optimal balance was achieved with Kp = 28, Ki = 10, Kd = 18 for motor 1 and Kp = 25, Ki = 6, Kd = 18 for motor 2, with a rise time of 211 s, minimal peak overshoot of 7.93%, and a steady-state error of -1.43°. Similar observations are reported by [4], who emphasised the sensitivity of PID parameters in achieving desired performance in robotic manipulators. These were further validated in subsequent speed vs. accuracy tests.

### 4.3 Accuracy Test

The accuracy test assessed the robotic arm’s precision in reaching designated positions within its operational workspace. Results demonstrated high accuracy near the workspace centre, with deviations as low as 2.83 mm. However, as the arm extended towards the periphery, deviations increased, reaching up to 85.34 mm. This trend is consistent with findings in robotic systems, where positional accuracy often diminishes at the extremities of the workspace due to factors like mechanical deflection and joint compliance.

### 4.4 Speed vs. Accuracy Test

The trade-off between speed and accuracy was evident in our experiments. Lower Kp values resulted in minimal positional deviations but required longer times to reach targets. In contrast, higher Kp values reduced response times but
compromised | accuracy, | with | deviations | increasing
significantly. This inverse relationship underscores the necessity of balancing speed and precision in robotic applications. The phenomenon aligns with the speed-accuracy trade-off observed in various robotic tasks, where increasing speed often leads to decreased accuracy.

### 4.1. Risk Assessment

The risk assessment of the robotic system was conducted using a Failure Mode and Effects Analysis (FMEA) approach, which systematically identified potential failure modes, hazardous situations, and critical mitigation strategies. This process ensured that risks across the mechanical, electrical, and software subsystems were evaluated and addressed to enhance the safety and reliability of the system. The risk assessment methodology included scoring each failure mode based on its likelihood, severity, and probability of leading to harm. High-risk items such as large unintended motion and H-bridge failures, received the highest criticality scores and were prioritised for mitigation. For instance, the risk of large uncontrolled motion at the tooltip, with a likelihood and catastrophic severity, was mitigated by implementing safety interlocks, PID tuning, and extensive testing. The full risk assessment table, including all identified risks and their mitigation plans, is available in Appendix B.

### 4.2. Limitations

One notable limitation was the decrease in accuracy near the boundaries of the workspace, where deviations were significantly higher due to mechanical instability and reduced manipulability. The rigid design of the robotic arm, while effective for centre positions, limited flexibility and adaptability in dynamic or complex trajectories.
The analytical kinematics approach, though computationally efficient, is restricted to well-defined workspaces and struggles near singularities. Alternative numerical methods such as DLS could provide robustness but were not implemented due to computational overhead. Additionally, the PID controller required manual tuning, making it less adaptable to changing tasks or environments.

### 4.3. Future Work

Adaptive control strategies, such as model predictive control or machine-learning-based PID tuning, could be integrated to dynamically adjust parameters in real time, improving performance across varying tasks. Incorporating more advanced kinematic methods, such as hybrid approaches that combine analytical and numerical solutions, could provide flexibility while maintaining computational efficiency.

### 5. CONCLUSION

This project successfully designed, developed, and tested a robotic arm capable of precise movements for drawing to different points within a 156 mm x 156 mm workspace. Through consideration of kinematic methods and PID control strategies, the robotic arm demonstrated accurate positioning and responsive performance. The use of analytical inverse kinematics provided efficient and direct solutions for joint angles, ensuring precision in the well-defined workspace. PID tuning allowed for an effective balance between speed and accuracy, with the optimal gains minimising overshoot while maintaining stability and fast response times. The accuracy tests highlighted the arm’s ability to achieve high precision near the workspace centre, though deviations increased at the boundaries due to mechanical and kinematic constraints. Similarly, the speed versus accuracy tests underscored the inherent trade-offs in PID-controlled systems, emphasising the importance of parameter optimisation for task-specific requirements. While the robotic arm performed effectively for its intended purpose, the project revealed several limitations, including accuracy degradation at workspace extremities and the lack of adaptability in control strategies. Addressing these challenges through adaptive control systems, improved mechanical design, and advanced manufacturing techniques would significantly enhance the arm’s functionality and versatility. In conclusion, the project demonstrated the feasibility of developing a low-cost, precise robotic arm for specialised tasks such as drawing. It provides a foundation for further research and development, paving the way for more robust and adaptable robotic systems for various applications.

### 6. REFERENCES

[1] J. J. C. S. Krovi, A. M. Okamura, and J. Rosen, "Guest editorial: Special issue on surgical robotics," IEEE/ASME Transactions on Mechatronics, vol. 20, 2015. [Online]. Available: https://web.eecs.umich.edu/~jjcorso/pubs/Krovi_SurgRob_SpIssue_DSC_Magazine_September2015.p df. (https://web.eecs.umich.edu/~jjcorso/pubs/Krovi_SurgRob_SpIssue_DSC_Magazine_September2015.pdf)
[1] J. J. C. S. Krovi, A. M. Okamura, and J. Rosen, "Guest editorial: Special issue on surgical robotics," IEEE/ASME Transactions on Mechatronics, vol. 20, 2015. [Online]. Available: https://web.eecs.umich.edu/~jjcorso/pubs/Krovi_SurgRob_SpIssue_DSC_Magazine_September2015.p df. (https://web.eecs.umich.edu/~jjcorso/pubs/Krovi_SurgRob_SpIssue_DSC_Magazine_September2015.pdf)
[2] H.-J. K. T. D. Le, and Q. V. Doan, "A method for optimal kinematic design of five-bar planar parallel manipulators," Proc. Int. Conf. on Control, Automation and Information Sciences 2013.
[3] A. Umamaheswara Rao and H. Arora, A Review of Methods Used for Kinematic Modeling of A Manipulator. 2017.
[4] J. Lin and Z. Z. Huang, "A novel PID control parameters tuning approach for robot manipulators mounted on oscillatory bases," Robotica, vol. 25, no. 4, pp. 467-477, 2007, doi: 10.1017/S0263574706003298.
[5] W. R. Library, "Introduction to PID Control," WPILib Documentation. [Online]. Available: https://docs.wpilib.org/en/stable/docs/software/advanced-controls/introduction/introduction-to-pid.html. (https://docs.wpilib.org/en/stable/docs/software/advanced-controls/introduction/introduction-to-pid.html)

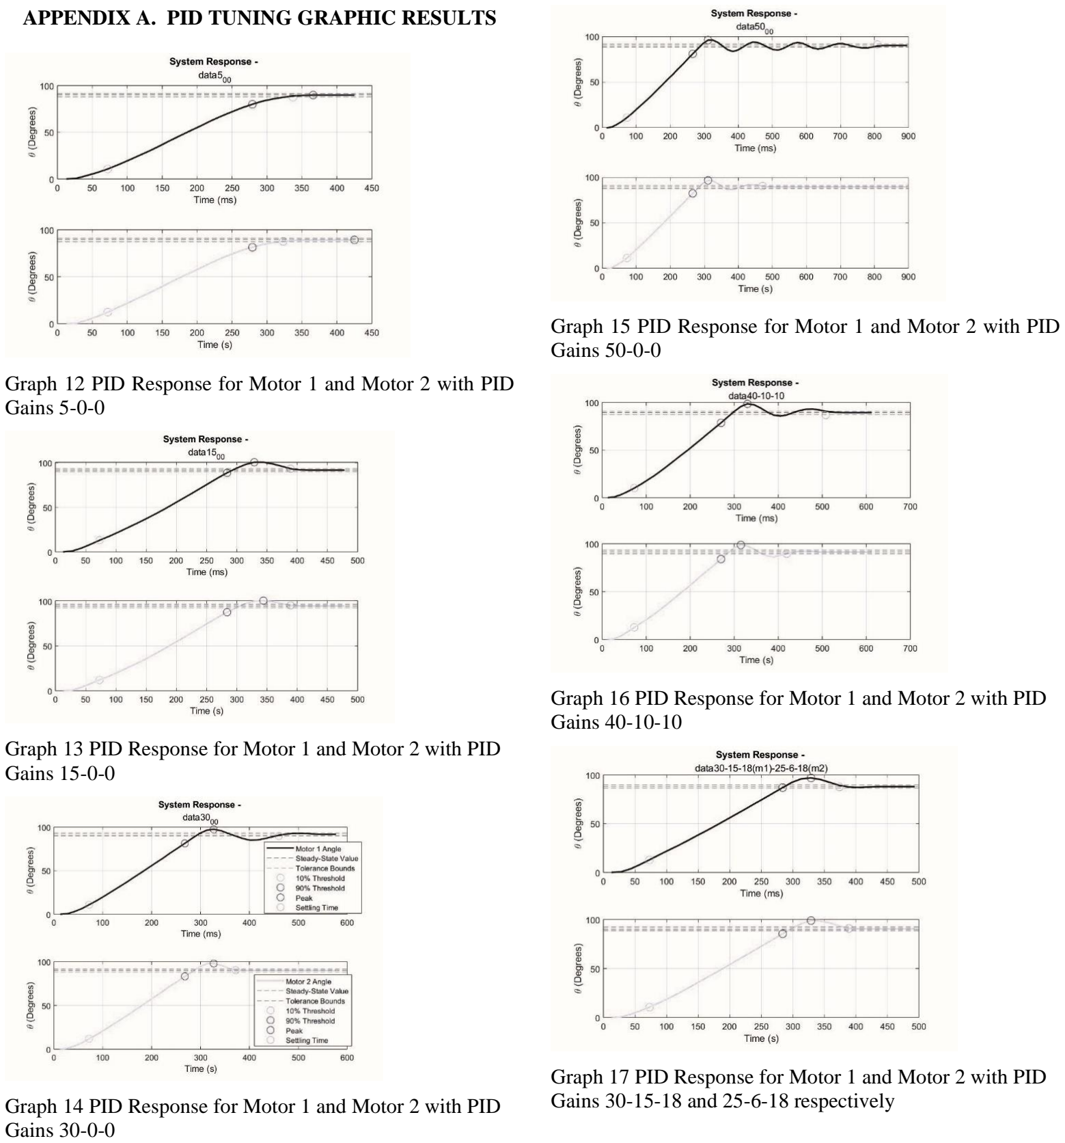
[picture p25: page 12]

APPENDIX A. PID TUNING GRAPHIC RESULTS

Graph 12 PID Response for Motor 1 and Motor 2 with PID Gains 5-0-0

Graph 13 PID Response for Motor 1 and Motor 2 with PID Gains 15-0-0

Graph 14 PID Response for Motor 1 and Motor 2 with PID Gains 30-0-0

Graph 15 PID Response for Motor 1 and Motor 2 with PID Gains 50-0-0

Graph 16 PID Response for Motor 1 and Motor 2 with PID Gains 40-10-10

Graph 17 PID Response for Motor 1 and Motor 2 with PID Gains 30-15-18 and 25-6-18 respectively

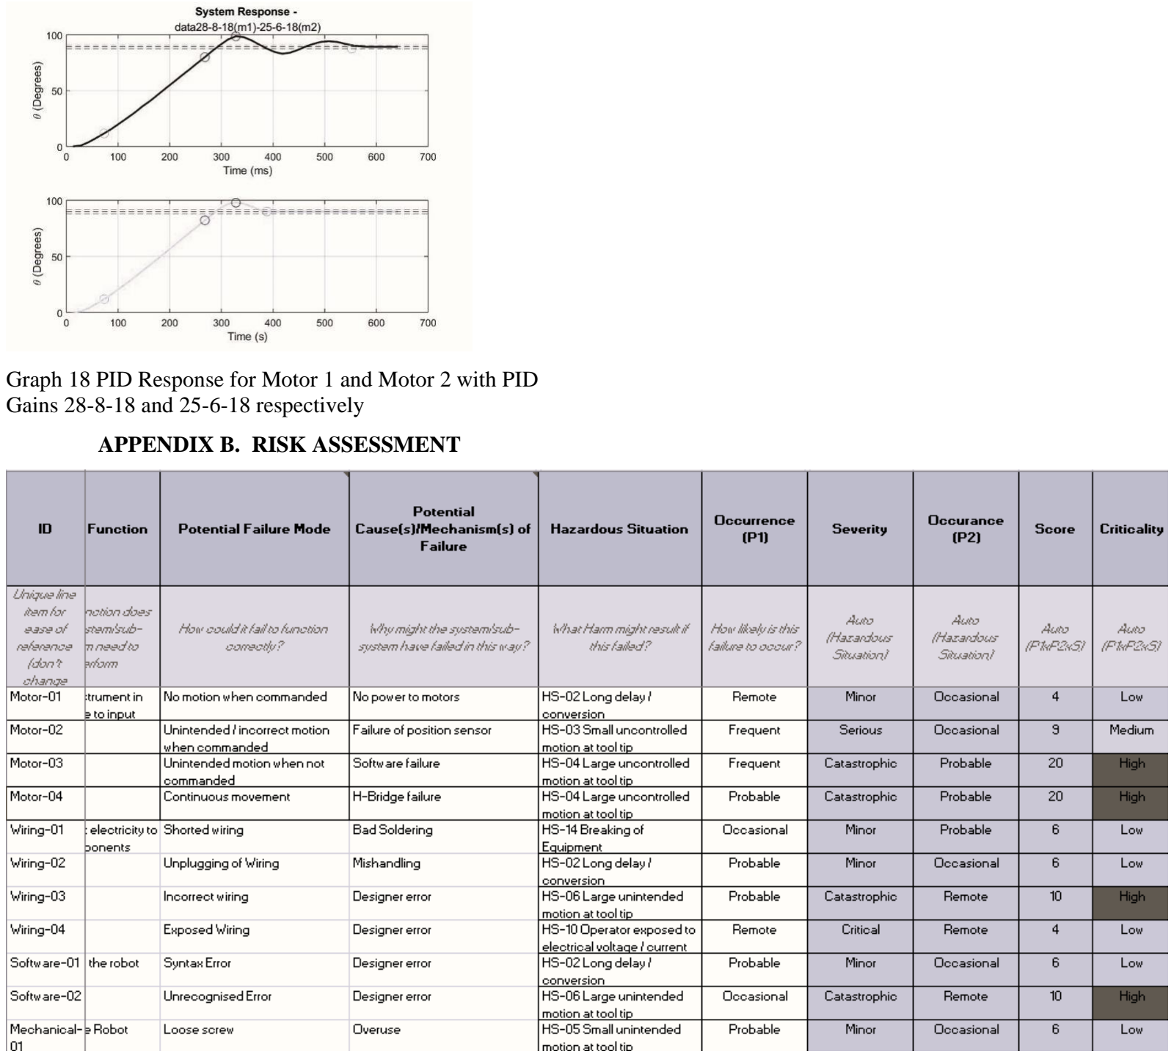
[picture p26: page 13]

Graph 18 PID Response for Motor 1 and Motor 2 with PID Gains 28-8-18 and 25-6-18 respectively

APPENDIX B. RISK ASSESSMENT

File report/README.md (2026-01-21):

# Report

- `Final_Applied_Robotics_Report.pdf` — full write-up of the design, control, and experiments.

For a quick overview and how to run the code, see the main repository `README.md`.

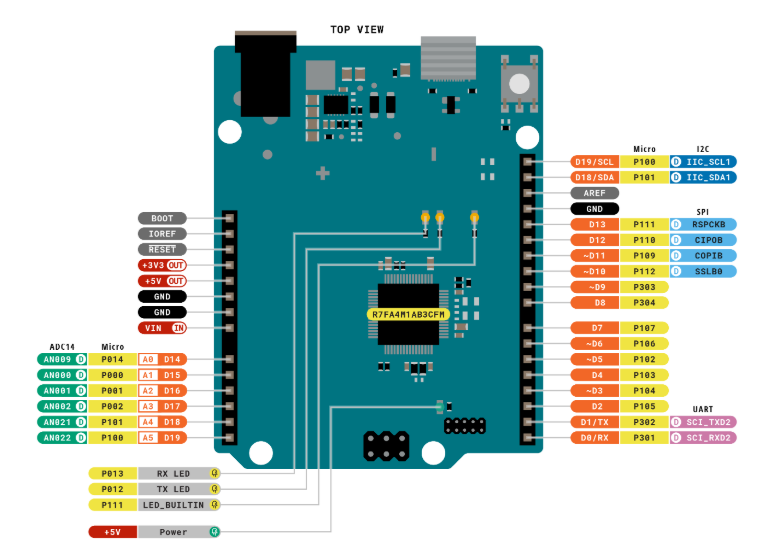
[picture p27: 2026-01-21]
media/diagrams/arduino_schematic.png

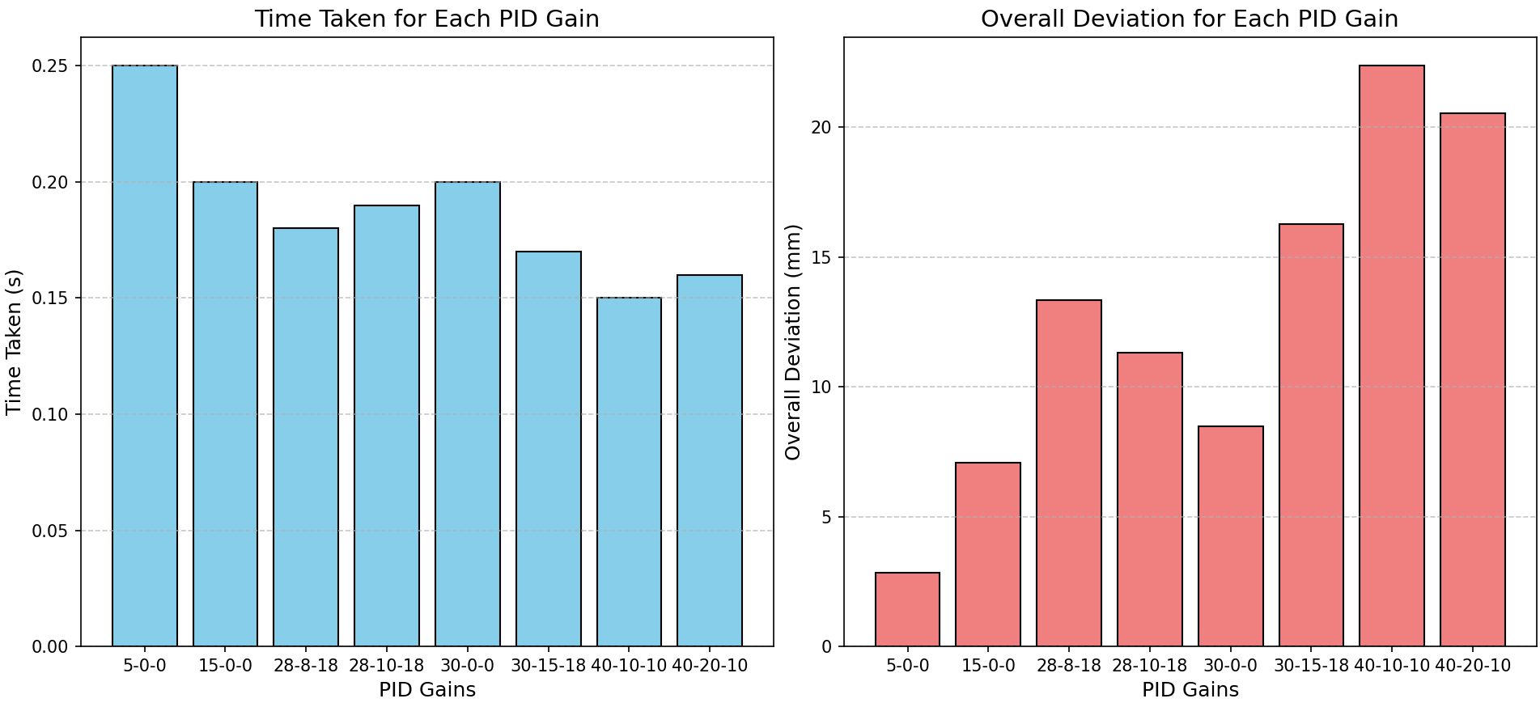
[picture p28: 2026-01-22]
media/plots/pid_errors.png

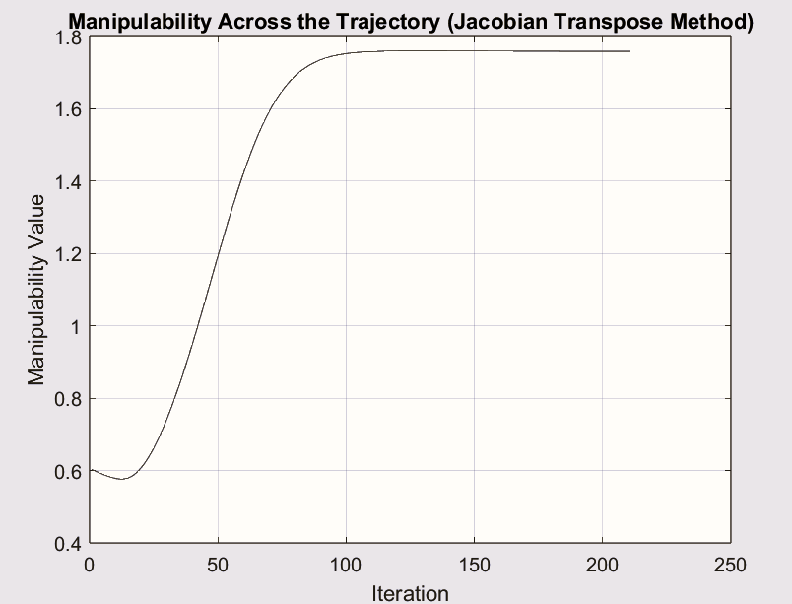
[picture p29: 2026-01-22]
media/plots/jacobian_transpose_mani.png

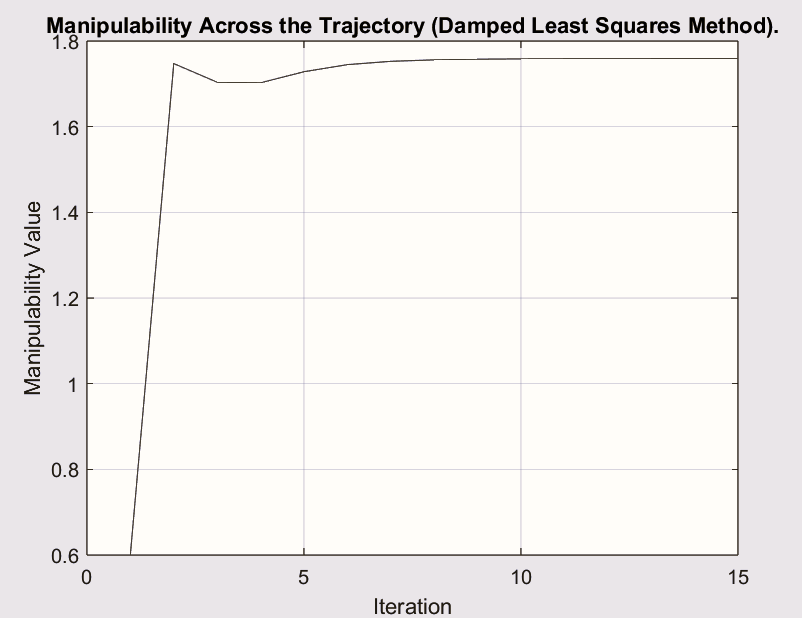
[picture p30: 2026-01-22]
media/plots/DLS_mani.png

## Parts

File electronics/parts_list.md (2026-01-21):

# Bill of Materials (BOM) — Drawing Robot Arm (2-DOF)

Quantities below match the physical robot build in this repo.

## Core electronics
- **1× Arduino Uno R4**
- **1× L298N dual H-bridge motor driver module**
- **2× DC geared motors with integrated potentiometer feedback** (5-wire)
- **1× 12V DC power supply (12V, 5A, 60W)**

## Wiring & connectors (direct-wired)
- **1× USB cable** (PC → Arduino, for programming + serial)
- **1× DC power connector / barrel jack (2.1 mm, 5A rated)** :contentReference[oaicite:1]{index=1}
- **Hook-up wire** (22–26 AWG recommended)
- **Solder + heatshrink** (or electrical tape)
- **Cable ties** (strain relief / cable management)

## Notes
- Ensure **common ground** between the 12V supply, L298N GND, and Arduino GND.
- Motors are powered from the **12V rail** via the L298N.
- Motor potentiometer feedback lines connect to Arduino analog inputs (see `firmware/README.md` for pin mapping).

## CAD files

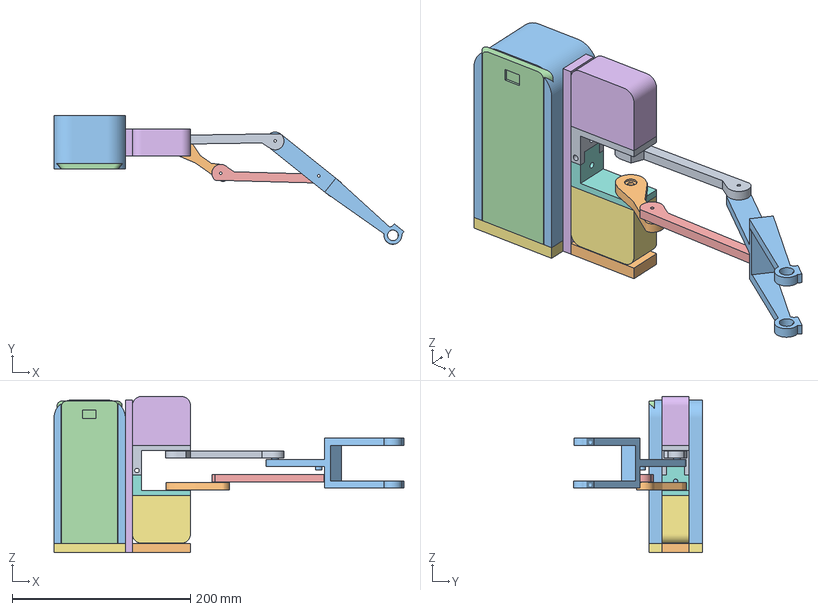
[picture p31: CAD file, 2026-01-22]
cad/print_files/3mf/final_assembly.3mf
392.5 x 144.3 x 175.0 mm
AGA61-01-Clutch ring x 2
Bottom Stand
Top Stand
base1
section 1 (l4)

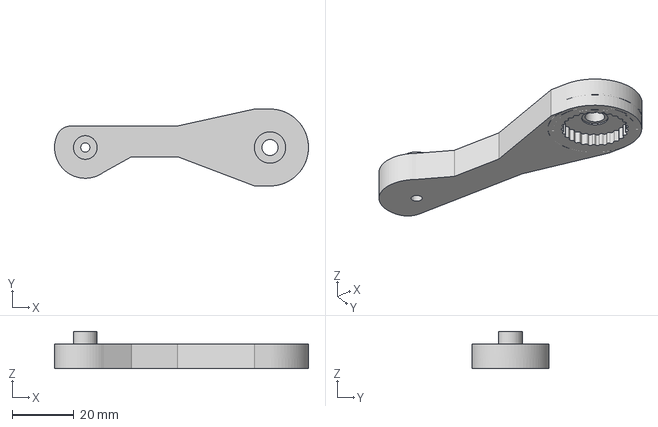
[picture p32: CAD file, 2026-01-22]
cad/print_files/3mf/link_4_ratcheting.3mf
82.5 x 25.0 x 12.1 mm

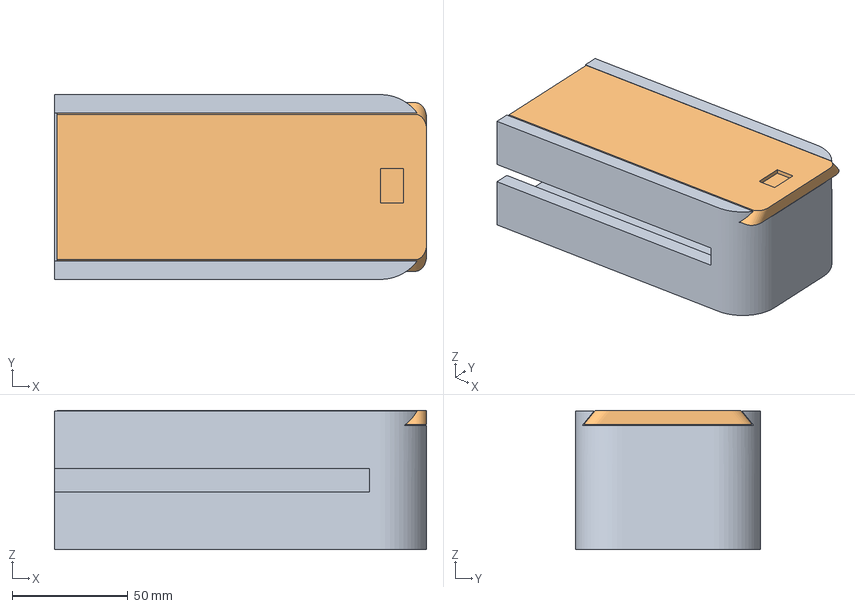
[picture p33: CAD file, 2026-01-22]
cad/print_files/3mf/box_cover_wiring.3mf
161.0 x 80.0 x 60.2 mm

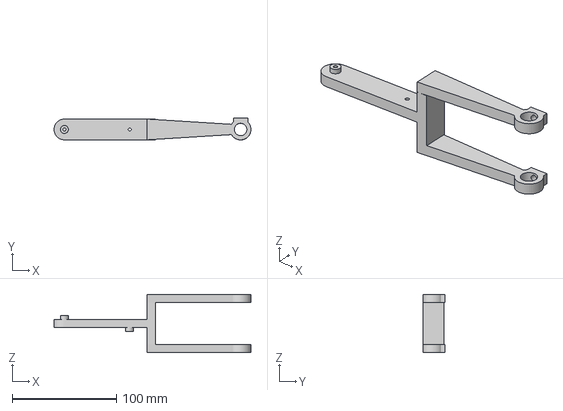
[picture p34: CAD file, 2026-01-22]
cad/print_files/3mf/link_2_end_effector.3mf
189.3 x 21.1 x 56.0 mm

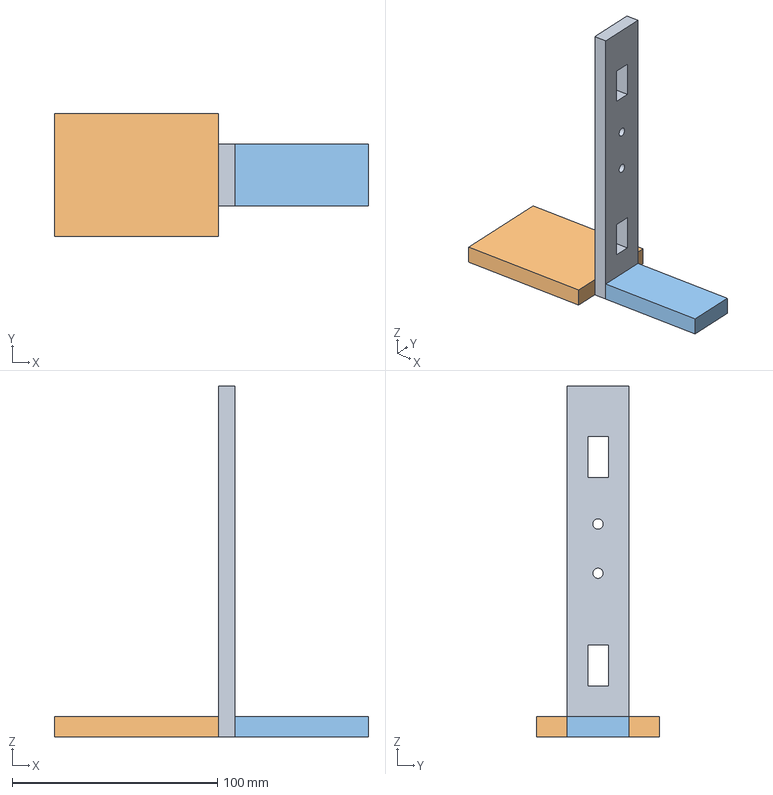
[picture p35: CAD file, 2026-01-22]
cad/print_files/3mf/base.3mf
153.0 x 60.0 x 171.0 mm
base1

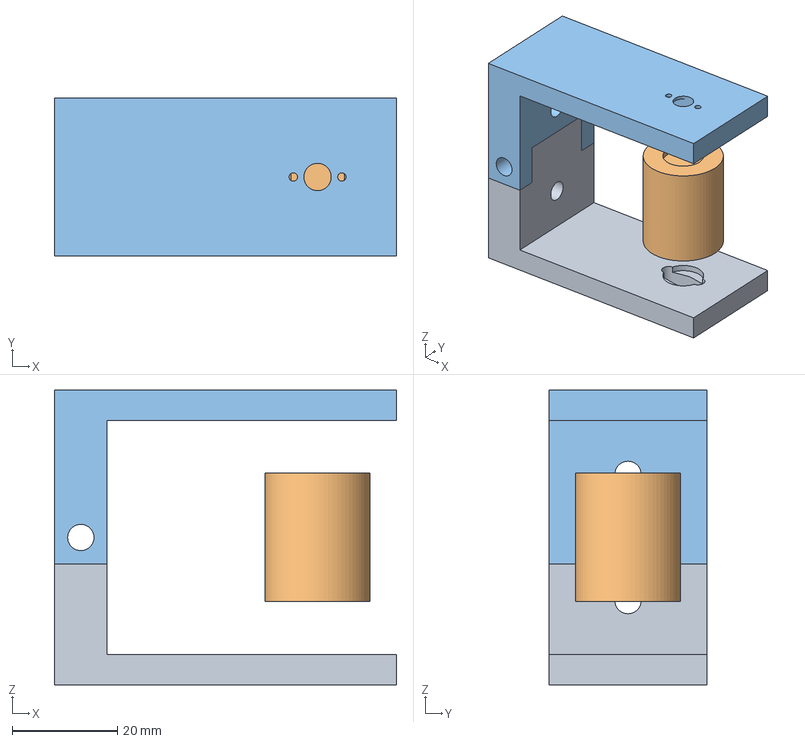
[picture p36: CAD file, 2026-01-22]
cad/print_files/3mf/motor_stand_central_piece.3mf
65.0 x 30.0 x 56.0 mm
Bottom Stand
Middle Piece
Top Stand

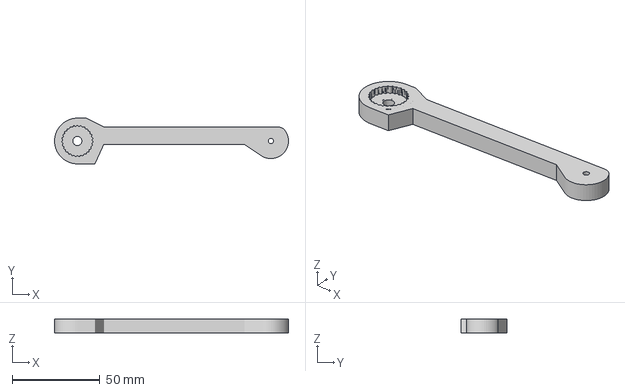
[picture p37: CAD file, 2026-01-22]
cad/print_files/3mf/link_1_ratcheting.3mf
133.0 x 26.0 x 8.03 mm

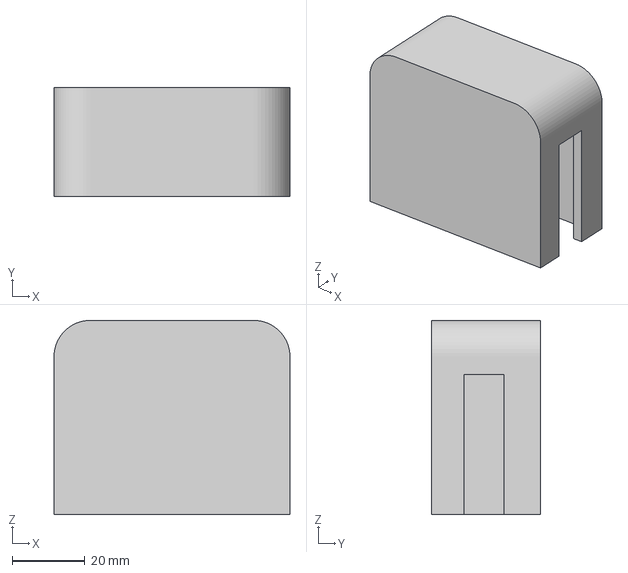
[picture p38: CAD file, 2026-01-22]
cad/print_files/3mf/cover_motor_bottom.3mf
65.0 x 30.0 x 53.5 mm

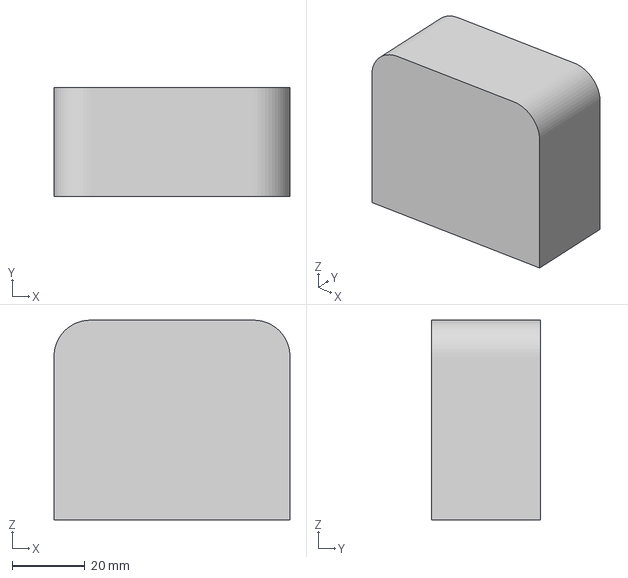
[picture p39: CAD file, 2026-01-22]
cad/print_files/3mf/cover_motor_top.3mf
65.0 x 30.0 x 55.0 mm

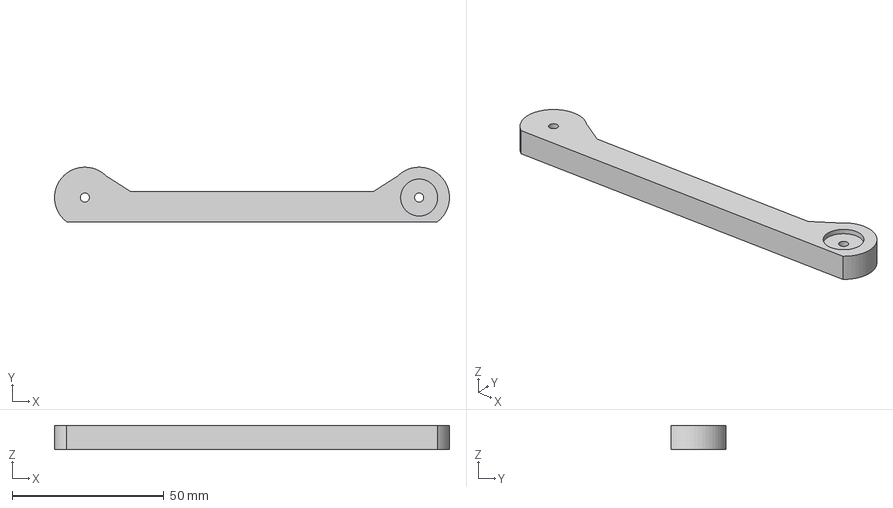
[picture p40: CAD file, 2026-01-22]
cad/print_files/3mf/link_3.3mf
130.0 x 18.0 x 8.00 mm

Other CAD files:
cad/fusion360/base.f3d
cad/fusion360/box_cover_wiring.f3d
cad/fusion360/cover_motor_bottom.f3d
cad/fusion360/cover_motor_top.f3d
cad/fusion360/final_assembly.f3z
cad/fusion360/link_1_ratcheting.f3d
cad/fusion360/link_2_end_effector.f3d
cad/fusion360/link_3.f3d
cad/fusion360/link_4_ratcheting.f3d
cad/fusion360/motor_stand_central_piece.f3d
cad/print_files/stl/base.stl
cad/print_files/stl/box_cover_wiring.stl
cad/print_files/stl/cover_motor_bottom.stl
cad/print_files/stl/cover_motor_top.stl
cad/print_files/stl/final_assembly.stl
cad/print_files/stl/link_1_ratcheting.stl
cad/print_files/stl/link_2_end_effector.stl
cad/print_files/stl/link_3.stl
cad/print_files/stl/link_4_ratcheting.stl
cad/print_files/stl/motor_stand_central_piece.stl

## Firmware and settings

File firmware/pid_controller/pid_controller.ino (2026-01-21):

/*
   7MRI0060 - Applied Medical Robotics Module
   October 2024
   Author: Alejandro Granados and Harry Robertshaw

   Purpose: Run a PID controller

   Tasks:
    1. Set pins to code
    2. Compute degrees and bound them to [-360,360]
    3. Compute elapsed time (deltaT) and control the frequency of printing
    4. Set demand position in degrees and compute errors (compared to previous, accumulation, and differential). 
       Hint: make sure you update previous error at the end.
    5. Compute PID
    6. Send voltage to motors
    7. Plot demand versus current position in degrees
*/

// Define constants for pulses per revolution (PPR) and gear ratio (GR)
const float PPR = 3575.0855;
const float GR = 297.924;
const float CPR = 3;

// Variables for tracking encoder positions
volatile long counter_m1 = 0;
volatile long counter_m2 = 0;
int aLastState_m1;
int aLastState_m2;

// Pins for reading encoders of motor 1 and 2
const int encoderPinA_m1 = A3;
const int encoderPinB_m1 = A2;

const int encoderPinA_m2 = A1;
const int encoderPinB_m2 = 11;

// Pins for setting the direction of motor 1 and 2
const int motorPin1_m1 = 4;
const int motorPin2_m1 = 5;
const int motorPin1_m2 = 7;
const int motorPin2_m2 = 8;

// Pins for setting the speed of rotation (Enable pin) of motors 1 and 2
const int enablePin_m1 = 6;
const int enablePin_m2 = 9;

// Variables for encoder positions and desired positions
long currentPosition_m1 = 0;
long currentPosition_m2 = 0;
float demandPositionInDegrees_m1 = 90.0;
float demandPositionInDegrees_m2 = 90.0;
float currentPositionInDegrees_m1;
float currentPositionInDegrees_m2;

// Time parameters
unsigned long currentTime;
unsigned long previousTime = 0;
unsigned long deltaT;
float windupGuard=70;

// PID gains
// current best: 55,0,1
float Kp_m1 = 55, Ki_m1 = 0, Kd_m1 = 1;
float Kp_m2 = 55, Ki_m2 = 0, Kd_m2 = 1;

// Error values
float errorPositionInDegrees_prev_m1 = 0, errorPositionInDegrees_sum_m1 = 0;
float errorPositionInDegrees_prev_m2 = 0, errorPositionInDegrees_sum_m2 = 0;

// Global variables
int i = 0;                // counter
String matlabStr = "";    // receives the string from matlab, it is empty at first
bool readyToSend = false; // flag to indicate a command was received and now ready to send back to matlab

char c;                   // characters received from matlab
float val1 = 0.0;         // input1 from matlab
float val2 = 0.0;         // input2 from matlab
int offset1 = 0.0;
int offset2 = 0.0;

void setup() {
  Serial.begin(9600);

  // Task 1: Initialize the pins using pinMode and attachInterrupt functions
  pinMode(motorPin1_m1, OUTPUT);
  pinMode(motorPin2_m1, OUTPUT);
  pinMode(enablePin_m1, OUTPUT);

  pinMode(motorPin1_m2, OUTPUT);
  pinMode(motorPin2_m2, OUTPUT);
  pinMode(enablePin_m2, OUTPUT);

  pinMode(encoderPinA_m1, INPUT_PULLUP);
  pinMode(encoderPinB_m1, INPUT_PULLUP);
  attachInterrupt(digitalPinToInterrupt(encoderPinA_m1), updateEncoder_m1, CHANGE);

  pinMode(encoderPinA_m2, INPUT_PULLUP);
  pinMode(encoderPinB_m2, INPUT_PULLUP);
  attachInterrupt(digitalPinToInterrupt(encoderPinA_m2), updateEncoder_m2, CHANGE);
  delay(3000);

  previousTime = micros();
}

void loop() {
  // Receive and parse data from MATLAB
  if (readyToSend == false) {
    if (Serial.available() > 0) {
      c = Serial.read();
      matlabStr += c;

      if (matlabStr.indexOf(";") != -1) {
        readyToSend = true;
        
        int posComma1 = matlabStr.indexOf(",");
        val1 = matlabStr.substring(1, posComma1).toFloat();
        int posEnd = matlabStr.indexOf(";");
        val2 = matlabStr.substring(posComma1 + 1, posEnd).toFloat();
        
        matlabStr = "";  // Clear string after parsing
        demandPositionInDegrees_m1 = val1 + offset1;
        demandPositionInDegrees_m2 = val2 + offset2;
      }
    }
  }
  
  // Task 2: Compute the current position in degrees and bound it to [-360,360]
  currentPositionInDegrees_m1 = ((counter_m1 * 360) / (CPR * GR * 2));
  currentPositionInDegrees_m2 = ((counter_m2 * 360) / (CPR * GR * 2));
  
  if (currentPositionInDegrees_m1 >= 360 || currentPositionInDegrees_m1 <= -360){
    counter_m1 -= ((CPR * GR * 2) * ((int)(currentPositionInDegrees_m1 / 360)));
  }
  if (currentPositionInDegrees_m2 >= 360 || currentPositionInDegrees_m2 <= -360){
    counter_m2 -= ((CPR * GR * 2) * ((int)(currentPositionInDegrees_m2 / 360)));
  }

  // Task 3: Compute elapsed time (deltaT) and control the frequency of printing
  currentTime = micros();
  deltaT = currentTime - previousTime;
  previousTime = currentTime;

if (deltaT > 400) {
    // Task 4: Compute error (P,I,D), and ensure that the previous error is updated
    // Calculate error for motor 1
    float errorPositionInDegrees_m1 = currentPositionInDegrees_m1 - demandPositionInDegrees_m1; 
    float errorPositionInDegrees_diff_m1 = (errorPositionInDegrees_m1 - errorPositionInDegrees_prev_m1) / deltaT; // Convert microseconds to seconds

    // Update the integral term with windup prevention
    errorPositionInDegrees_sum_m1 += errorPositionInDegrees_m1 * deltaT;
    // Update integral in seconds

    // Optionally clamp the integral term to prevent windup
    errorPositionInDegrees_sum_m1 = constrain(errorPositionInDegrees_sum_m1, -windupGuard, windupGuard);

    // Update previous error
    errorPositionInDegrees_prev_m1 = errorPositionInDegrees_m1;

    // Calculate error for motor 2
    float errorPositionInDegrees_m2 = currentPositionInDegrees_m2 - demandPositionInDegrees_m2; 
    float errorPositionInDegrees_diff_m2 = (errorPositionInDegrees_m2 - errorPositionInDegrees_prev_m2) / deltaT; // Convert microseconds to seconds

    // Update the integral term for motor 2 with windup prevention
    errorPositionInDegrees_sum_m2 += errorPositionInDegrees_m2 * deltaT; // Update integral in seconds
    errorPositionInDegrees_sum_m2 = constrain(errorPositionInDegrees_sum_m2, -windupGuard, windupGuard);

    // Update previous error
    errorPositionInDegrees_prev_m2 = errorPositionInDegrees_m2;

    // Task 5: Compute the PID output for motor 1
    float controllerOutput_m1 = (Kp_m1 * errorPositionInDegrees_m1) + 
                                 (Ki_m1 * errorPositionInDegrees_sum_m1) + 
                                 (Kd_m1 * errorPositionInDegrees_diff_m1);
    controllerOutput_m1 = constrain(controllerOutput_m1, -255, 255);

    // Compute the PID output for motor 2
    float controllerOutput_m2 = (Kp_m2 * errorPositionInDegrees_m2) + 
                                 (Ki_m2 * errorPositionInDegrees_sum_m2) + 
                                 (Kd_m2 * errorPositionInDegrees_diff_m2);
    controllerOutput_m2 = constrain(controllerOutput_m2, -255, 255);

    // Task 6: Send voltage to 
    if (controllerOutput_m1 > 0) {
      digitalWrite(motorPin1_m1, HIGH);
      digitalWrite(motorPin2_m1, LOW);
      analogWrite(enablePin_m1, controllerOutput_m1);
    } else {
      digitalWrite(motorPin1_m1, LOW);
      digitalWrite(motorPin2_m1, HIGH);
      analogWrite(enablePin_m1, -controllerOutput_m1);
    }

    if (controllerOutput_m2 > 0) {
      digitalWrite(motorPin1_m2, HIGH);
      digitalWrite(motorPin2_m2, LOW);
      analogWrite(enablePin_m2, controllerOutput_m2);
    } else {
      digitalWrite(motorPin1_m2, LOW);
      digitalWrite(motorPin2_m2, HIGH);
      analogWrite(enablePin_m2, -controllerOutput_m2);
    }
  }

  if (readyToSend)  // arduino has received command form matlab and now is ready to send
  {
    // e.g. c1,100,100
    Serial.print("c");                    // command
    Serial.print(i);                      // series 1
    Serial.print(",");                    // delimiter
    Serial.print(currentPositionInDegrees_m1);
    Serial.print(",");
    Serial.print(currentPositionInDegrees_m2); // series 2
    Serial.write(13);                     // carriage return (CR)
    Serial.write(10);                     // new line (NL)
    i += 1;
  }
}

// Interrupt functions for tracking the encoder positions
void updateEncoder_m1() {
  // Code to update counter_m1 based on the state of the encoder pins
  // Read current states of channels A and B
  int aState_m1 = digitalRead(encoderPinA_m1);
  int bState_m1 = digitalRead(encoderPinB_m1);

  // Check if the state of channel A has changed
  if (aState_m1 != aLastState_m1) {
    // Determine the direction of rotation by comparing A and B states
    if (aState_m1 != bState_m1) {
      counter_m1++;  // Clockwise rotation
    } else {
      counter_m1--;  // Counterclockwise rotation
    }
  }

  // Update the last known state of channel A
  aLastState_m1 = aState_m1;
}

void updateEncoder_m2() {
  // Code to update counter_m2 based on the state of the encoder pins
  // Read current states of channels A and B
  int aState_m2 = digitalRead(encoderPinA_m2);
  int bState_m2 = digitalRead(encoderPinB_m2);

  // Check if the state of channel A has changed
  if (aState_m2 != aLastState_m2) {
    // Determine the direction of rotation by comparing A and B states
    if (aState_m2 != bState_m2) {
      counter_m2++;  // Clockwise rotation
    } else {
      counter_m2--;  // Counterclockwise rotation
    }
  }

  // Update the last known state of channel A
  aLastState_m2 = aState_m2;
}
